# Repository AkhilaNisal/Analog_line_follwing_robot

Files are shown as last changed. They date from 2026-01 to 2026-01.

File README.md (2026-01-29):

# 🛣️ Analog Line Following Robot (Fully Analog PID)

<p align="center">
  <b>A microcontroller-free line following robot using pure analog signal processing</b>
</p>

<p align="center">
  Designed & built by <b>Team Outlaws</b> <br>
  Department of Electronic & Telecommunication Engineering <br>
  University of Moratuwa, Sri Lanka
</p>

---

## 🎥 Full Demo Video

<p align="center">
  <a href="Media/Media1.mp4">
    
  </a>
  <a href="Media/circle.mp4">
    
  </a>
</p>

---

## 📸 Robot Overview

### Front View & PCB
<p align="center">
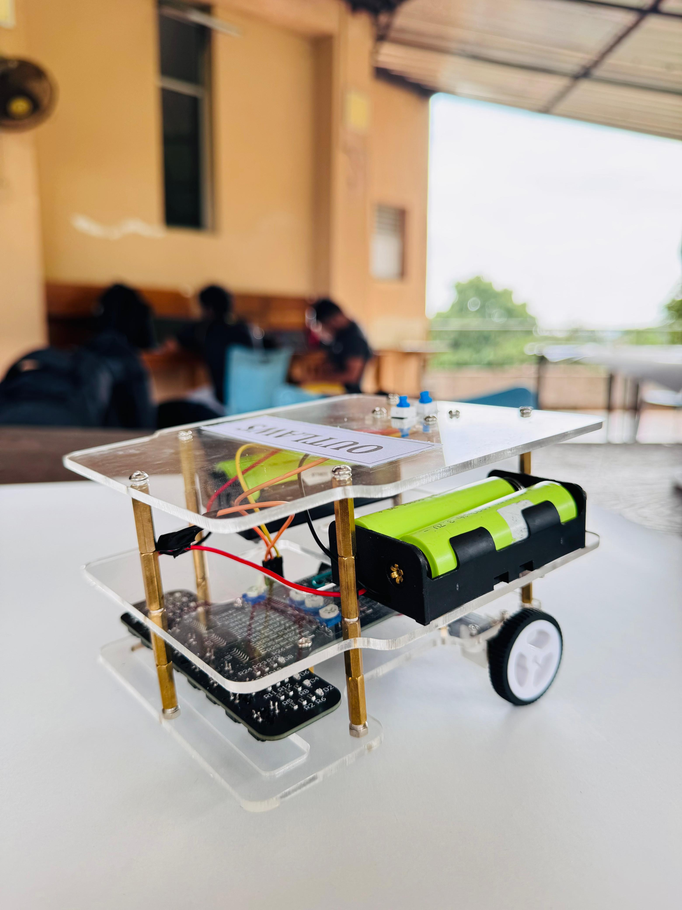
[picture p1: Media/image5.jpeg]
  

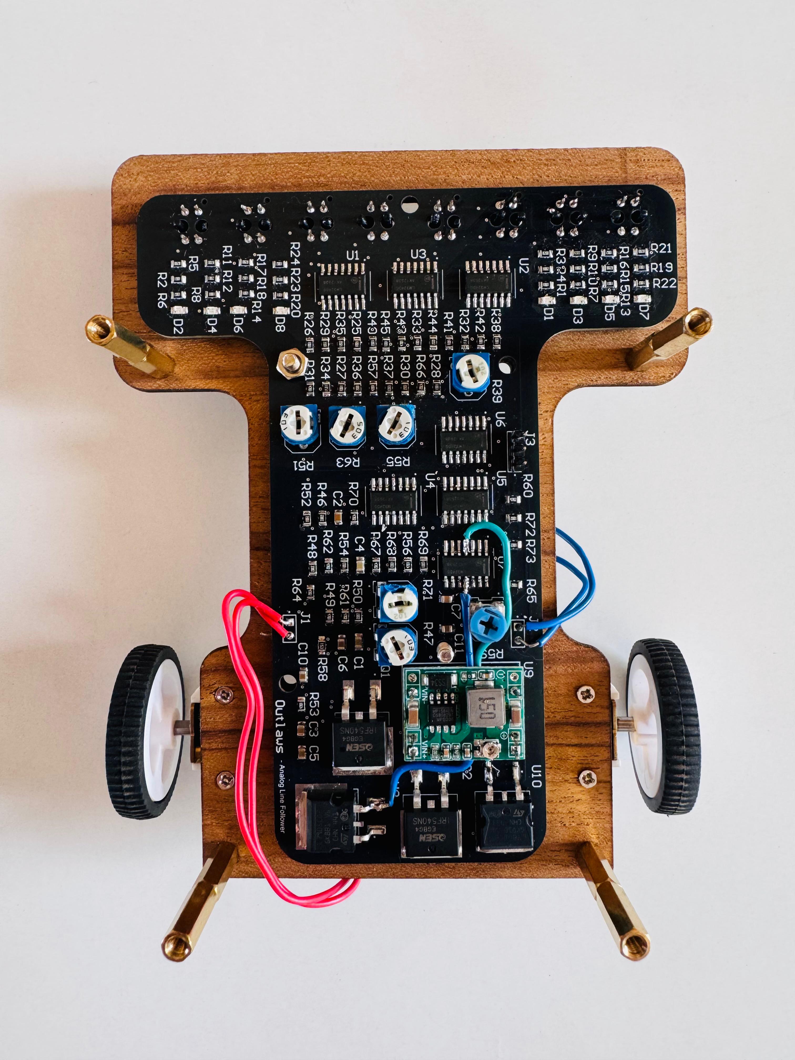
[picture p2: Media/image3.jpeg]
  
</p>

---

## 🧠 System Architecture (Purely Analog)

This project presents a **fully analog line-following robot**, where **all sensing, control,
and actuation are implemented using analog circuits only** — no microcontroller, no
firmware, and no digital computation.

The system operates as follows:

- **8-channel IR sensor array (TCRT5000)** generates continuous analog voltages
- **Buffer circuits** isolate sensor outputs
- **Weighted scaling adders** compute left and right positional values
- **Differential amplifier** produces the line error signal
- **Fully analog PID controller (LM324)** computes corrective action
- **Analog PWM generator** (triangle wave + comparator) converts control signal to PWM
- **Transistor-based motor drivers** actuate DC motors

This architecture enables **real-time, low-latency, deterministic control**.

---

## ⚙️ Key Features

- 🔌 **100% Analog Control System**
- 📡 **Continuous sensor feedback**
- 🎚️ **Adjustable P, I, D gains**
- ⚡ **Low-latency real-time response**
- 🧩 **Custom 2-layer SMD PCB**
- 🖨️ **3D-printed enclosure**
- 🧪 **Simulation-verified & hardware-tested**

---

## 🖥️ Simulation & Hardware Testing

- PID stability verified through circuit simulation
- PWM waveform validated using oscilloscope measurements
- Smooth line tracking with minimal overshoot

---

## 🧑‍🤝‍🧑 Team Outlaws

<p>
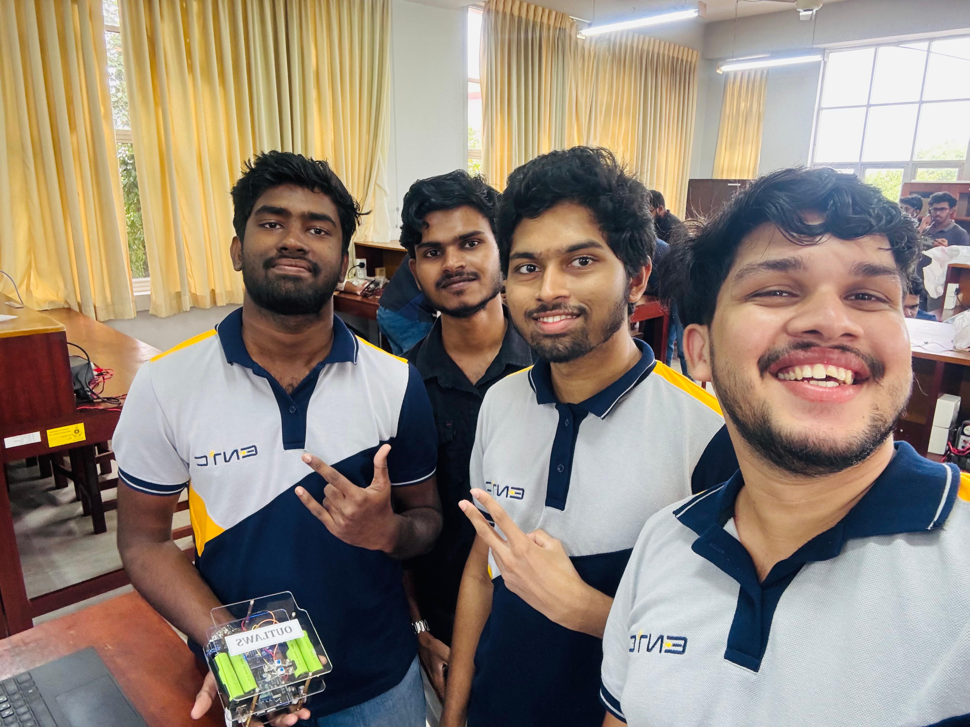
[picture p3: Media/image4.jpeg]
  
</p>

| Name | Index No | Contribution |
|---|---|---|
| A.N. Wedamestrige | 230687P | Circuit design, simulation & debugging |
| R.J.K.O.H. Ranathunga | 230525U | Circuit analysis & enclosure design |
| M.N. Kumarasinghe | 230355X | PCB design |
| W.V.M.J. Himasara | 230248X | Soldering & hardware testing |

---

## 📄 Documentation

📘 Full technical report available in this repository:  
`17_Outlaws_EN2091_Analog_Project.pdf`

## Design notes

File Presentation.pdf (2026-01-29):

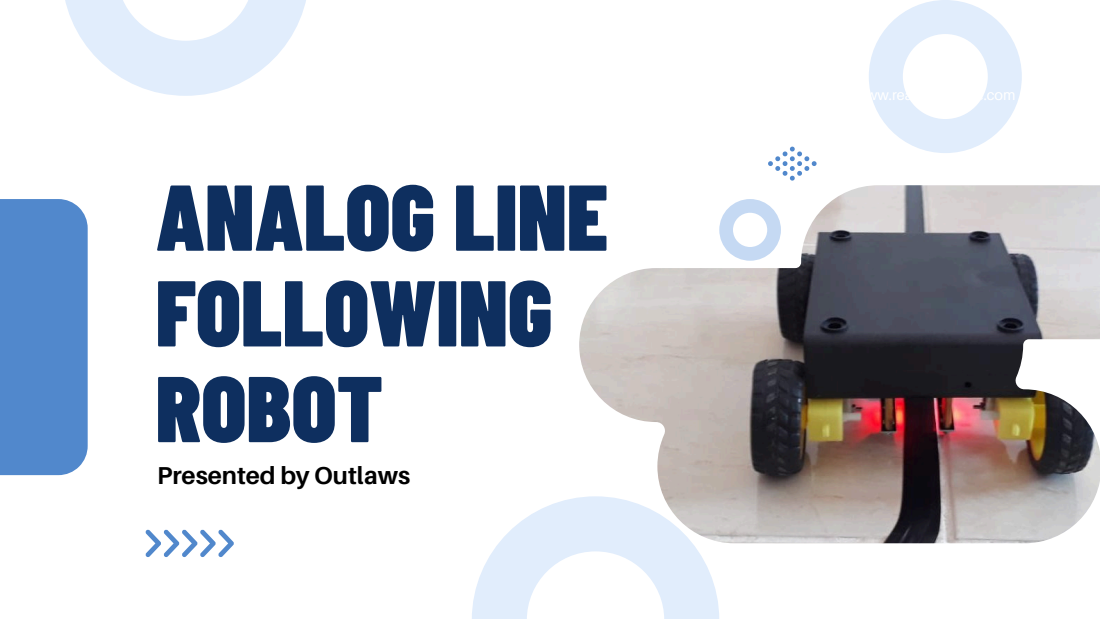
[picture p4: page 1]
ANALOG LINE FOLLOWING ROBOT

www.reallygreatsite.com

Presented by Outlaws

# Project Overview

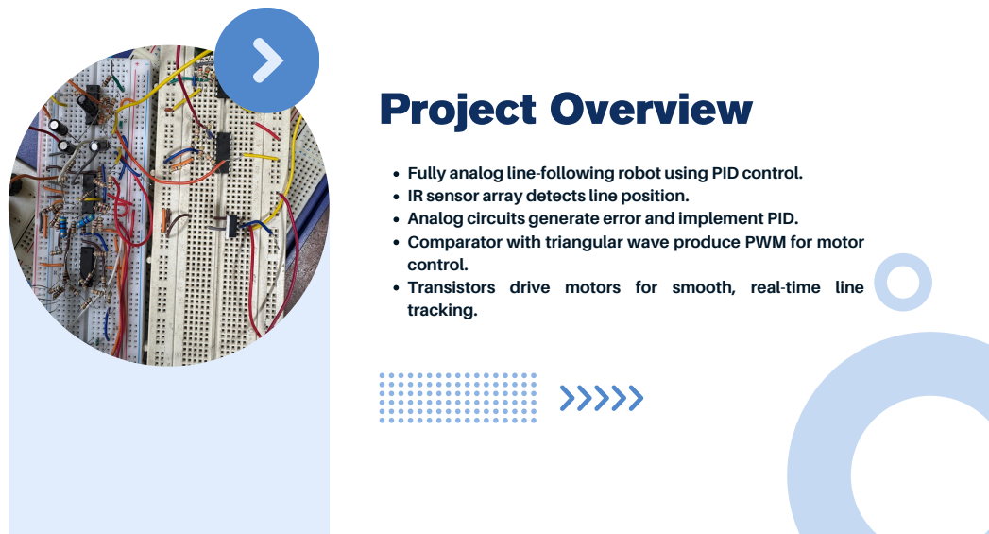
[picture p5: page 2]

Fully analog line-following robot using PID control.
IR sensor array detects line position.
Analog circuits generate error and implement PID.
Comparator with triangular wave produce PWM for motor
control.
Transistors drive motors for smooth, real-time line
tracking.

# Components and Selection

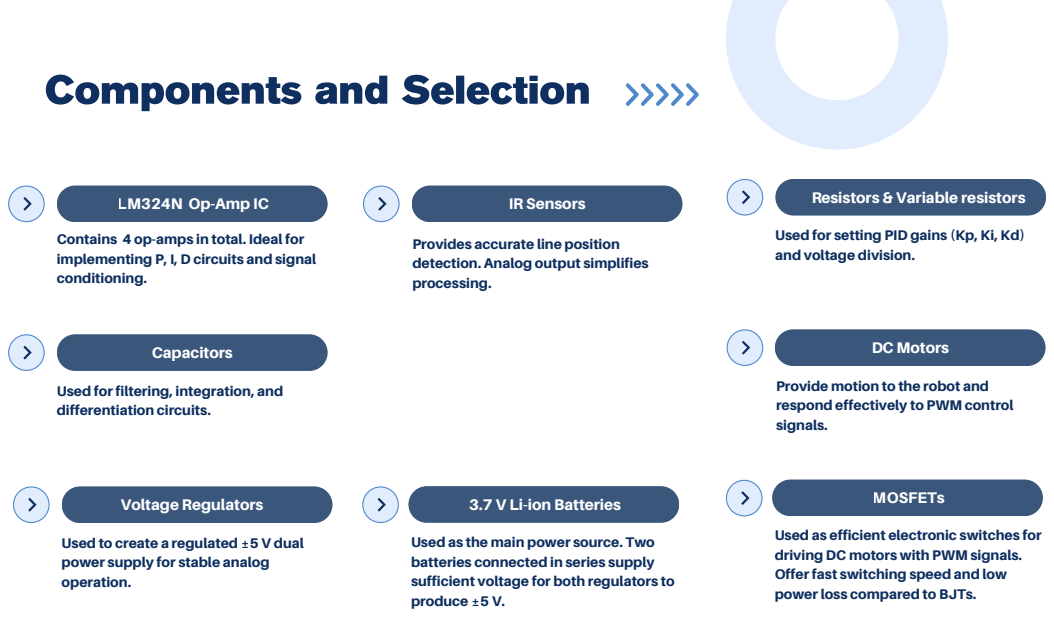
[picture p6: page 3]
IR Sensors; Capacitors; Voltage Regulators; DC Motors; MOSFETs

Resistors & Variable resistors

LM324N Op-Amp IC

Used for setting PID gains (Kp, Ki, Kd)
and voltage division.

Contains 4 op-amps in total. Ideal for
implementing P, I, D circuits and signal
conditioning.

Provides accurate line position
detection. Analog output simplifies
processing.

Provide motion to the robot and
respond effectively to PWM control
signals.

Used forfiltering, integration, and
differentiation circuits.

3.7 V Li-ion Batteries

Used as efficient electronic switches for
driving DC motors with PWM signals.
Offerfast switching speed and low
powerloss compared to BJTs.

Used as the main power source. Two
batteries connected in series supply
sufficient voltage for both regulators to
produce ±5 V.

Used to create a regulated ±5 V dual
power supply for stable analog
operation.

# System Block Diagram

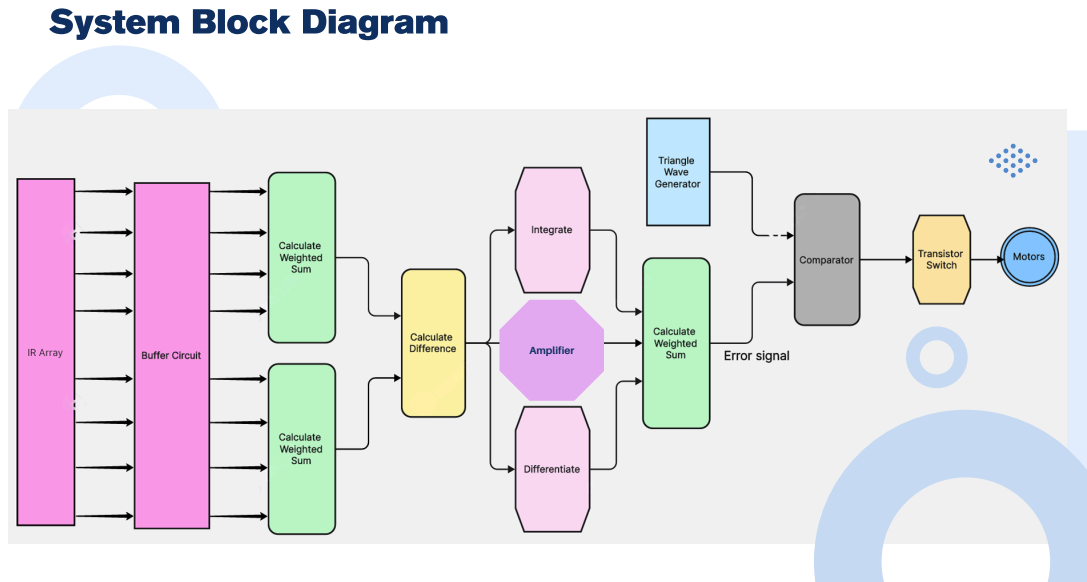
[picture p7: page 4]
Amplifier

# Functionality

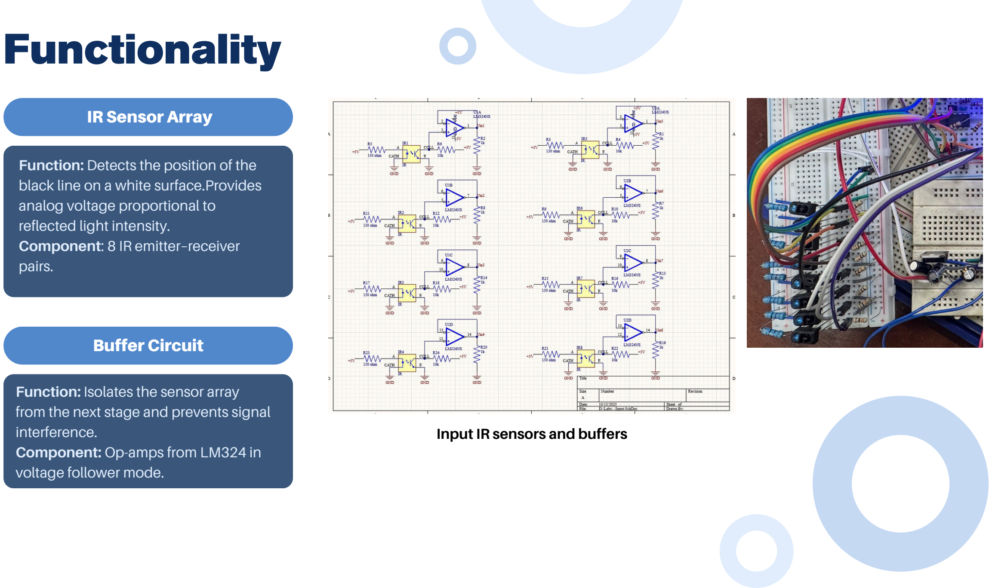
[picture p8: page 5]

Buffer Circuit

Function: Detects the position of the black line on a white surface.Provides analog voltage proportional to reflected light intensity.
Component: 8 IR emitter–receiver pairs.

IR Sensor Array

Function: Isolates the sensor array from the next stage and prevents signal interference.
Component: Op-amps from LM324 in voltage follower mode.

Input IR sensors and buffers

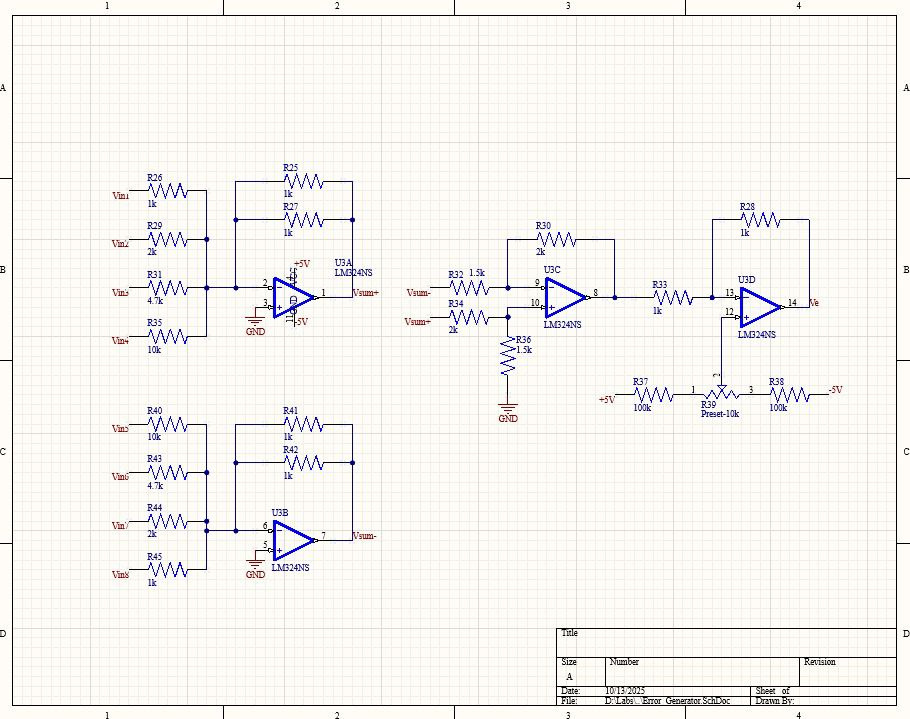
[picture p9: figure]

Scaling adders and Subtractor

Weighted Sum Calculation

Function: Computes position information by giving different weights to each sensor.
Component: Scaling adder circuit using op-amps and resistors.

Calculate Difference

Function: Produces the error signal by comparing left and right sums. Component: Differential amplifier

# Functionality

# Functionality

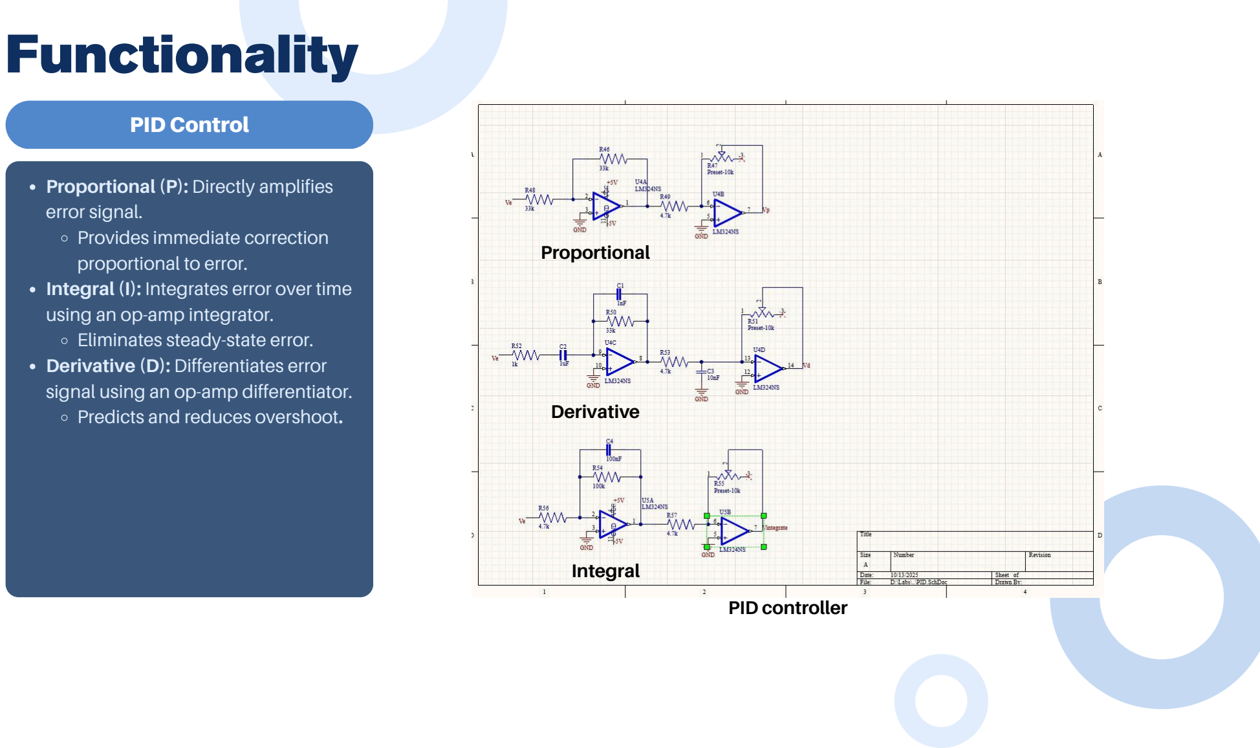
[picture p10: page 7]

PID Control

Proportional (P): Directly amplifies error signal.
Provides immediate correction proportional to error.
Integral (I): Integrates error over time using an op-amp integrator. Eliminates steady-state error. Derivative (D): Differentiates error signal using an op-amp differentiator. Predicts and reduces overshoot.

PID controller

Proportional

Derivative

Integral

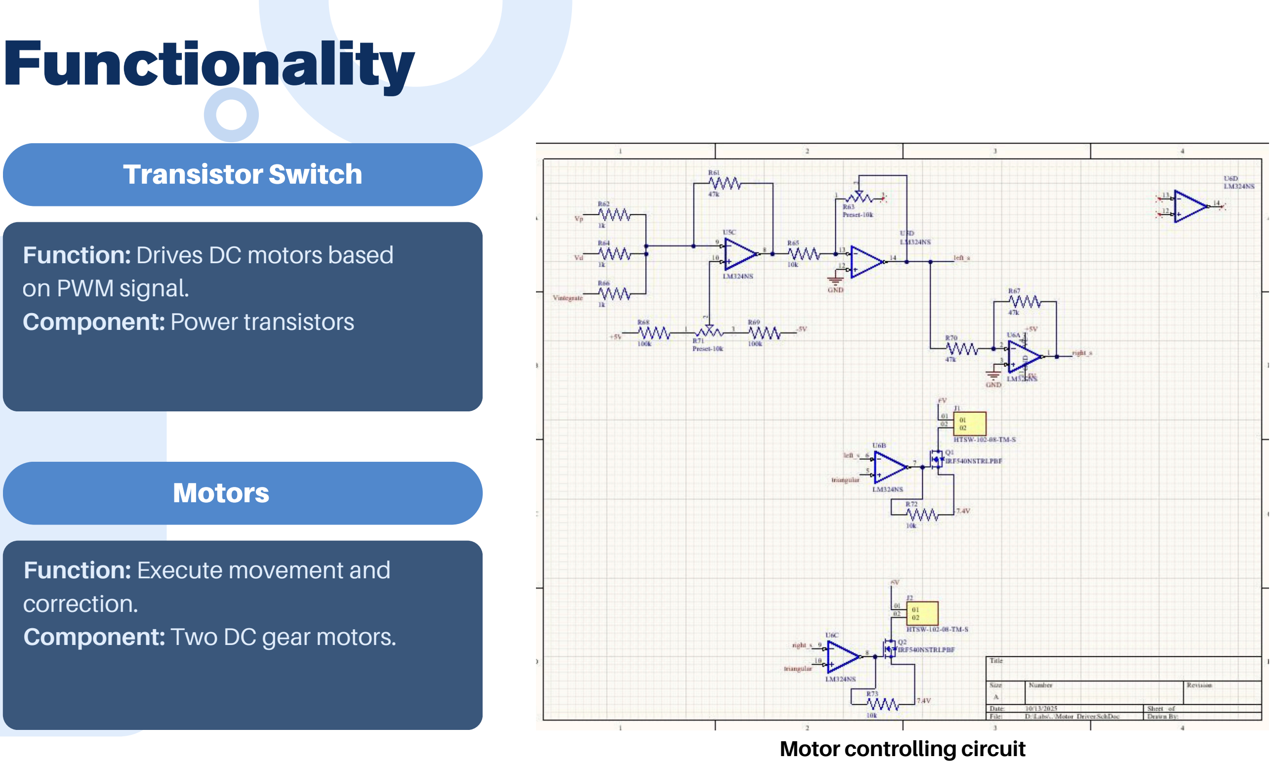
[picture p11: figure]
Transistor Switch; on PWM signal.; Motors; Function: Execute movement and correction. Component: Two DC gear motors.; Motor controlling circuit; Functionality

Function: Drives DC motors based Component: Power transistors

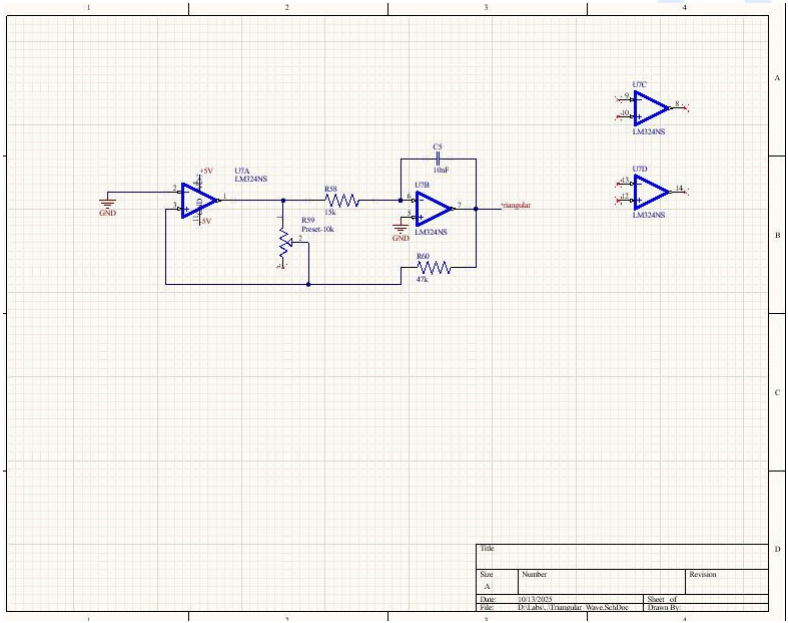
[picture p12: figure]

Triangular wave generator

## Comparator

Function: Produces a periodic triangle waveform.
Component: Op-amp-based
integrator + comparator.

## Triangle Wave Generator

Function: Compares PID output with triangle wave to generate PWM. Component: Op-amp in comparator mode.

# Functionality

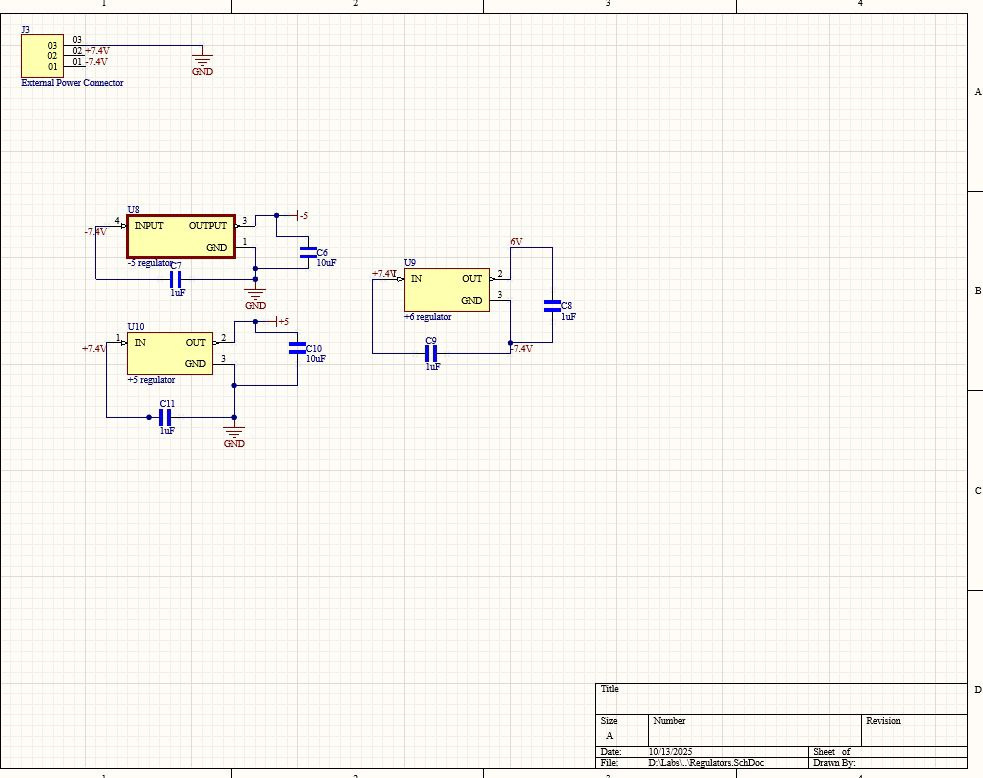
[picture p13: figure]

Regulators and power management circuits

# PCB Design

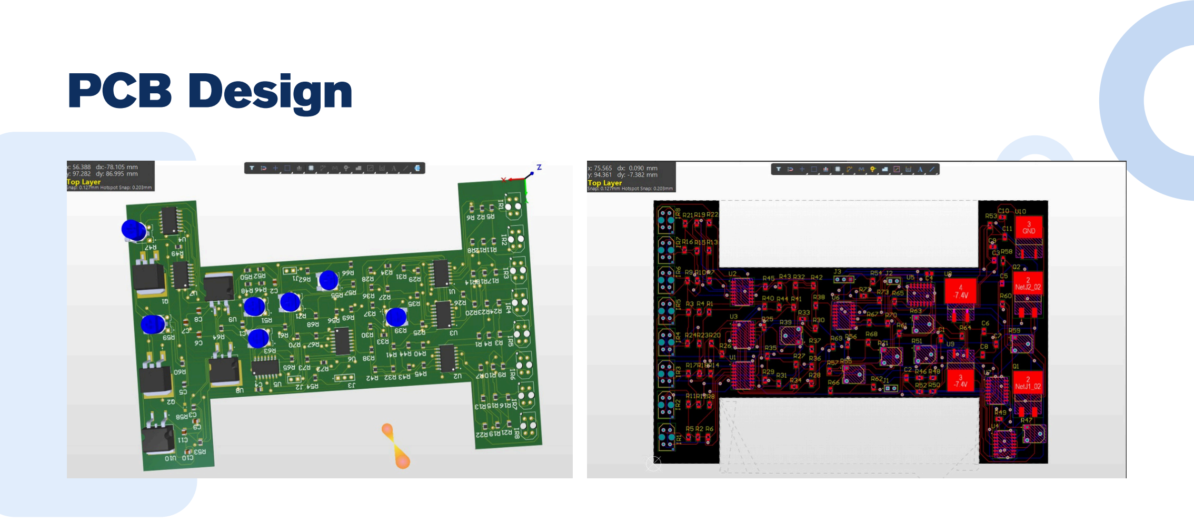
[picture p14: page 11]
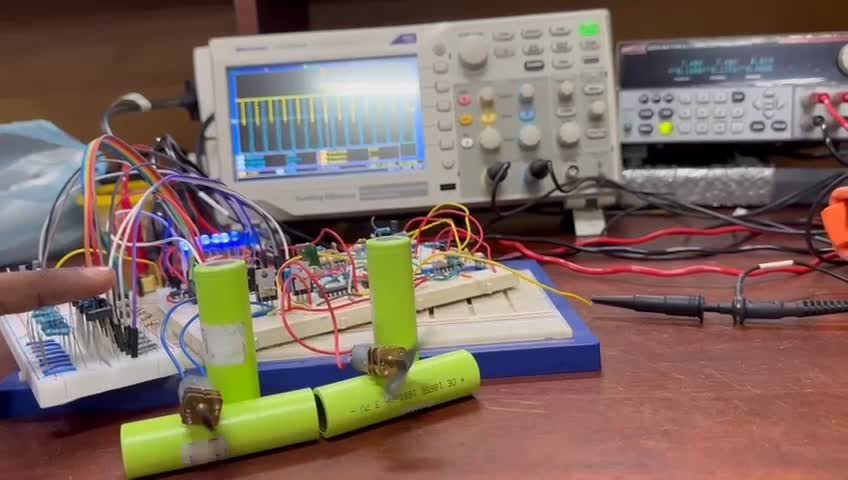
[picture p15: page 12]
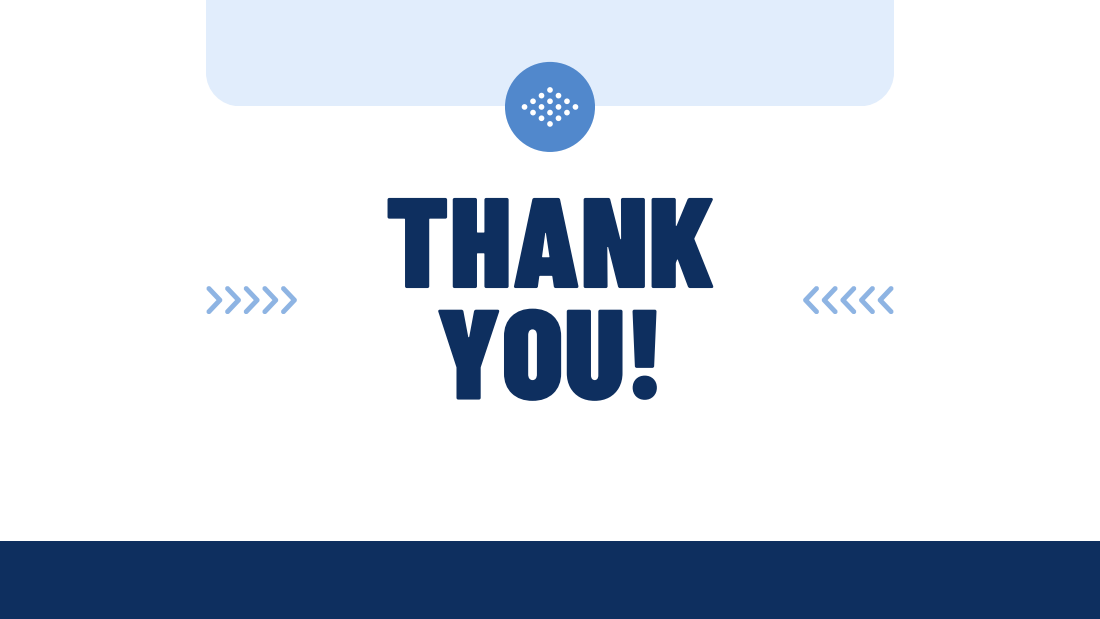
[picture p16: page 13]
THANK YOU!

www.reallygreatsite.com

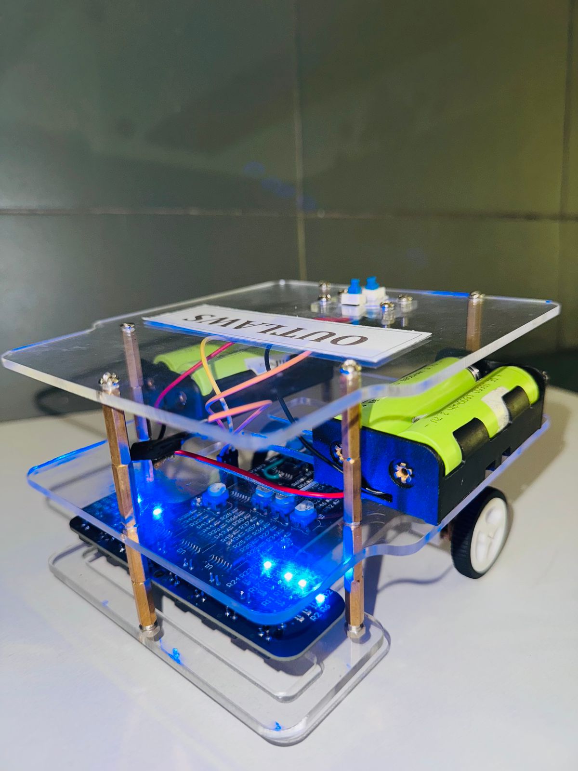
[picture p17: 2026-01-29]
Media/image.jpg

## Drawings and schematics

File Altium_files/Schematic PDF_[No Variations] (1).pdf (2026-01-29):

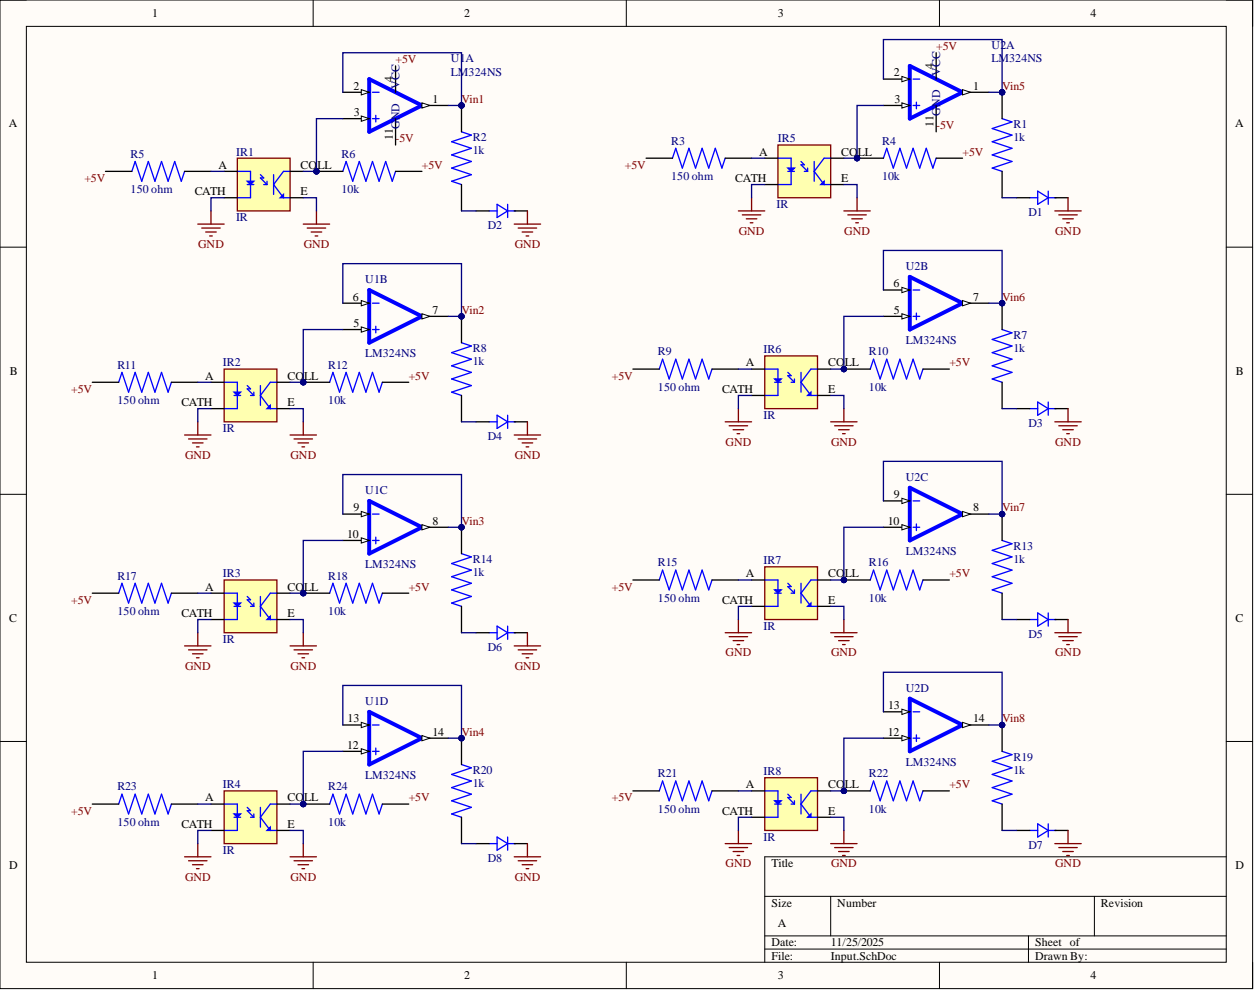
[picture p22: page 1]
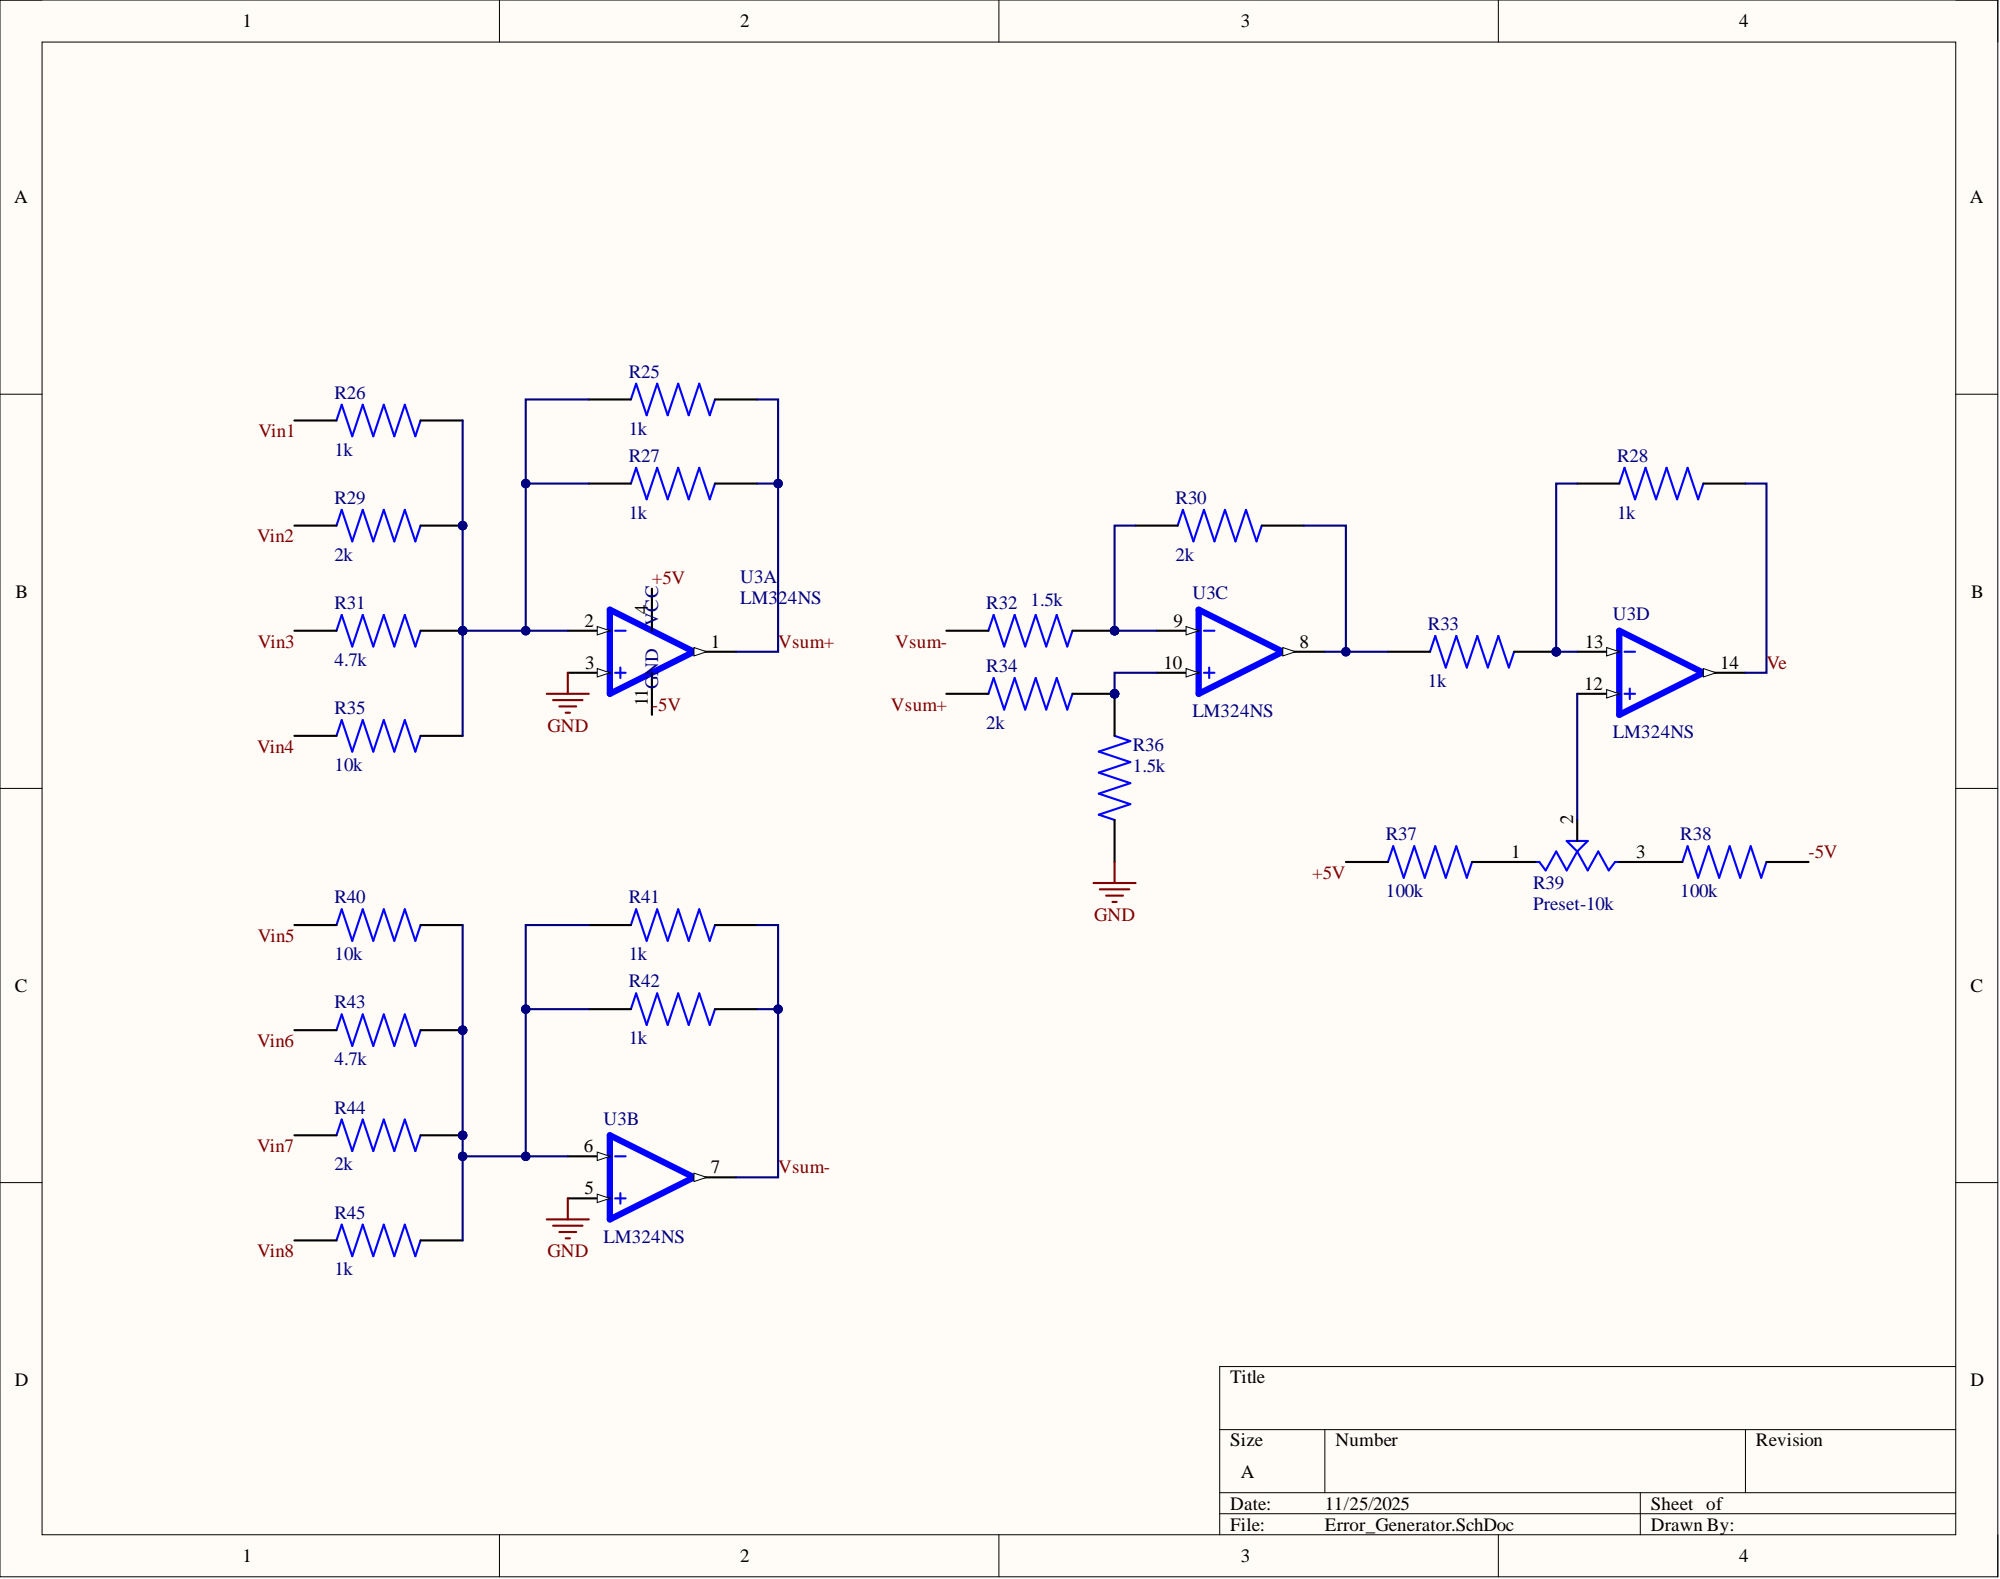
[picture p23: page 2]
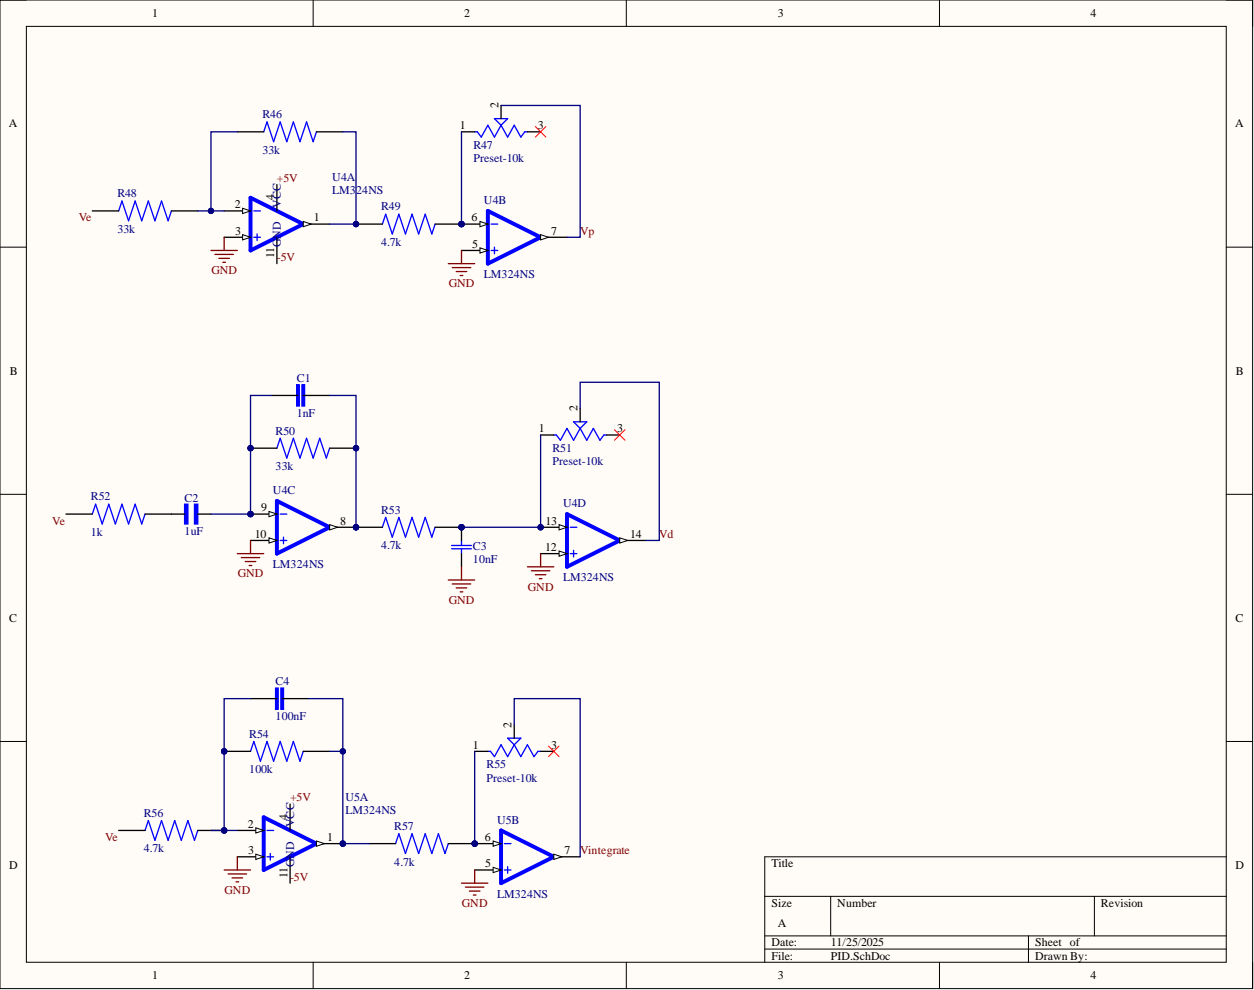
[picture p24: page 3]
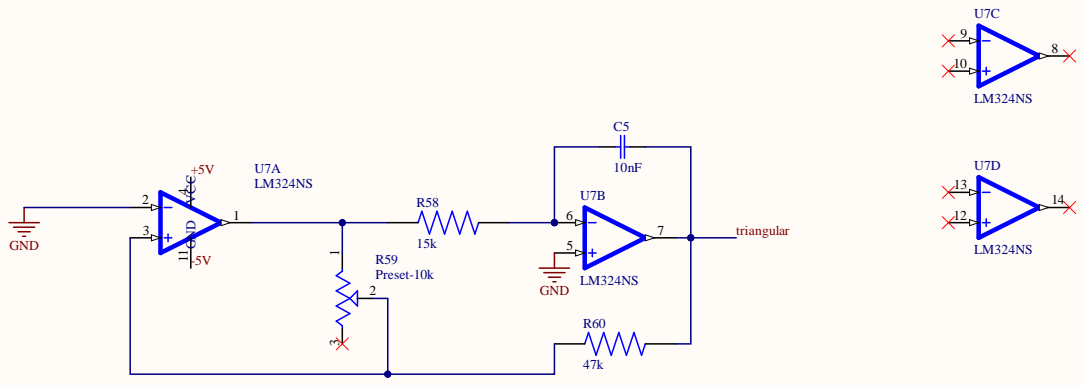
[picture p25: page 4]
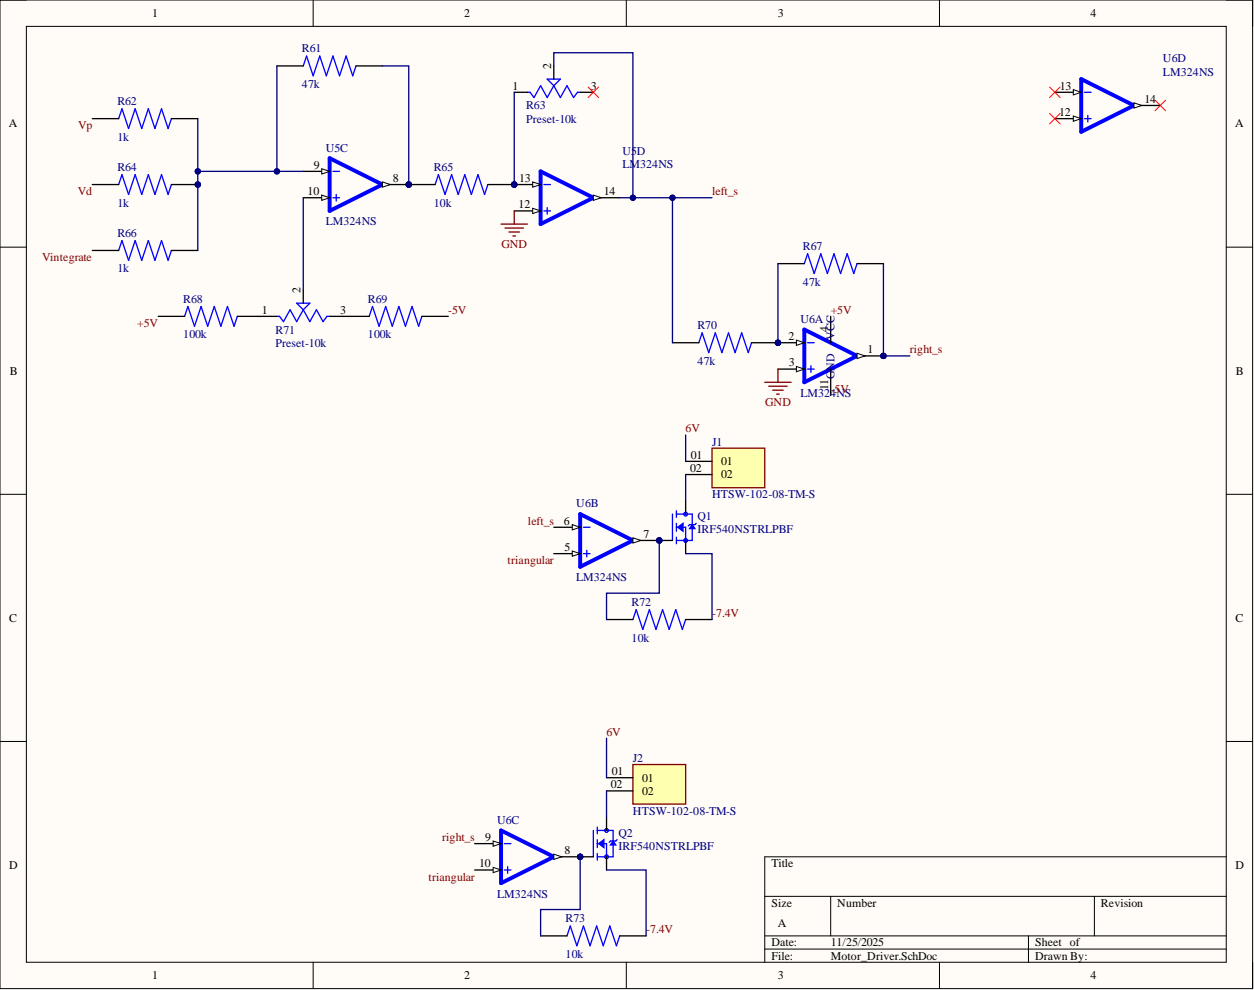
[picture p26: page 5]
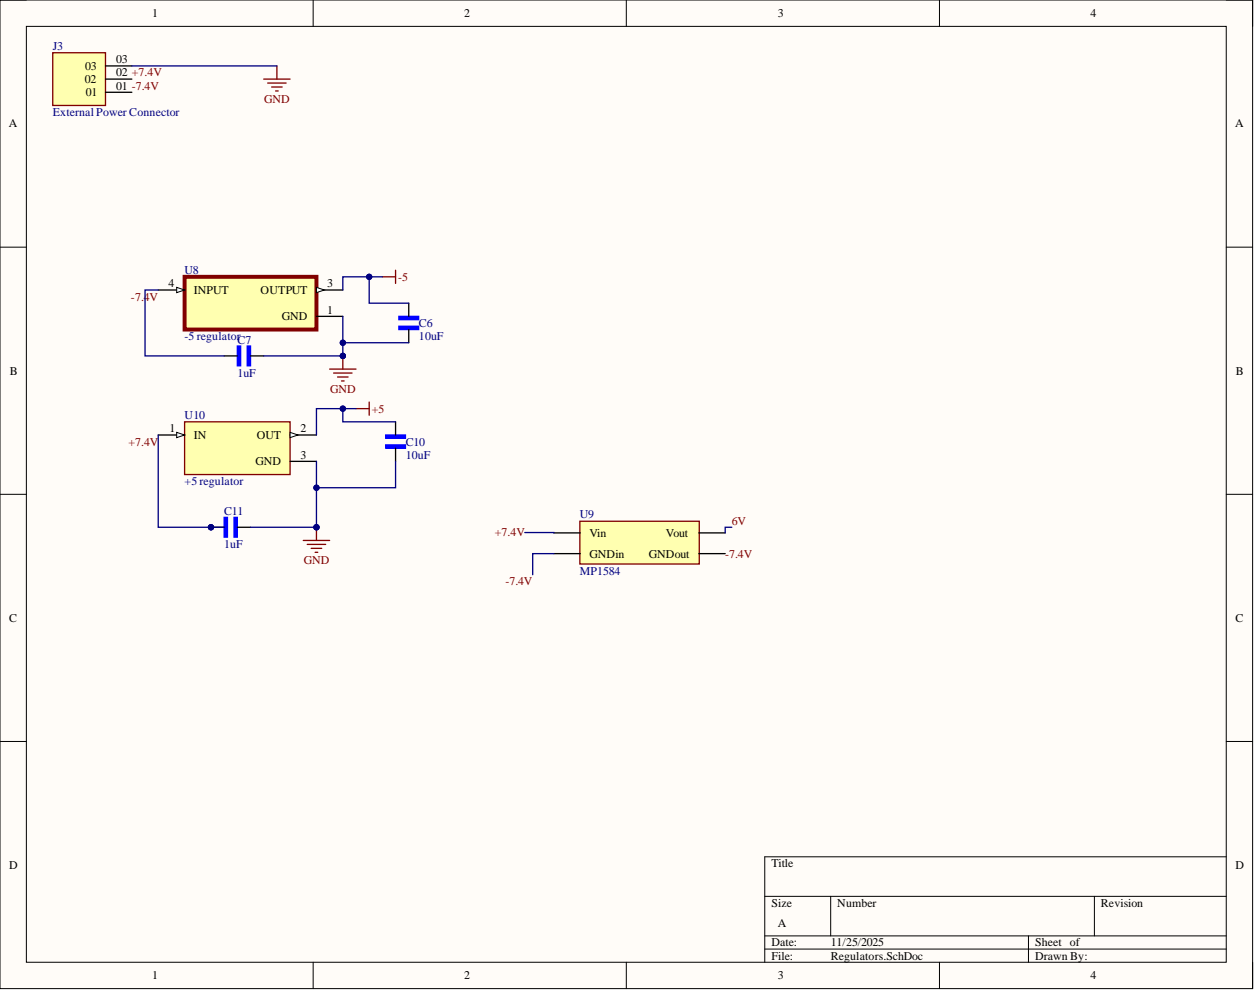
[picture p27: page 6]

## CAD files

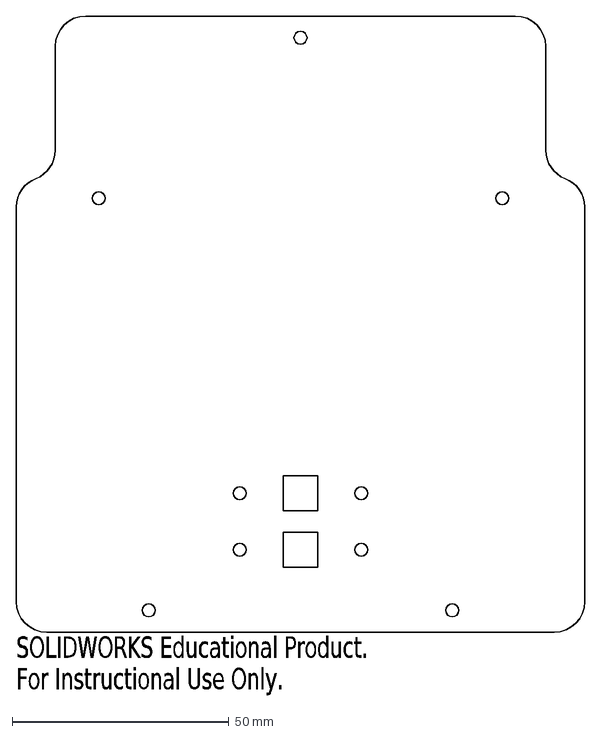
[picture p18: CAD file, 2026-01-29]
Solidworks/upper_top.DXF
SOLIDWORKS Educational Product.
For Instructional Use Only.

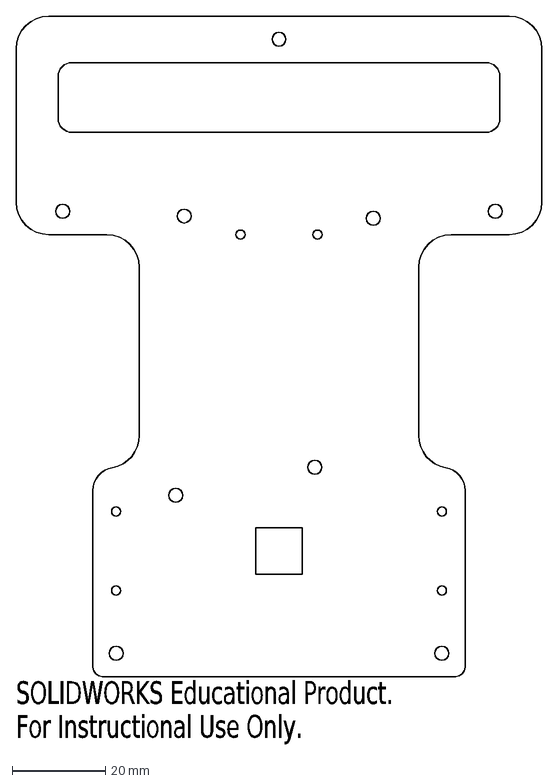
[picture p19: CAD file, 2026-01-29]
Solidworks/lower.DXF
SOLIDWORKS Educational Product.
For Instructional Use Only.

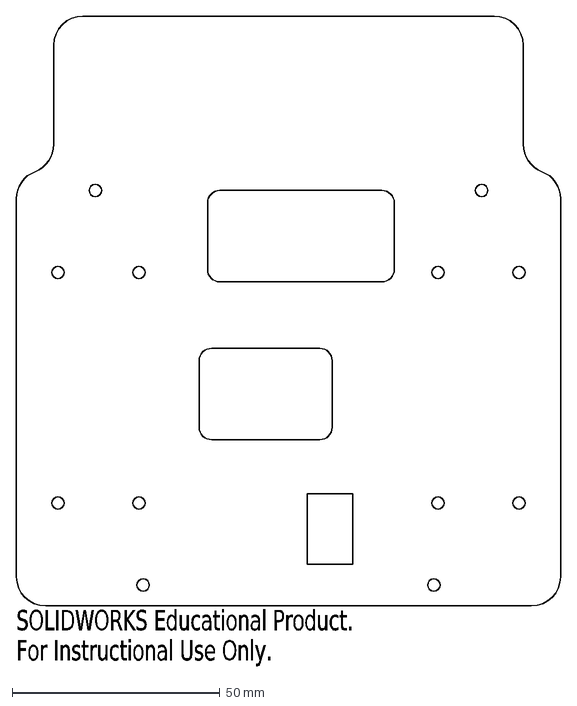
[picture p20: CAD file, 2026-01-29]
Solidworks/upper_acrilic.DXF
SOLIDWORKS Educational Product.
For Instructional Use Only.

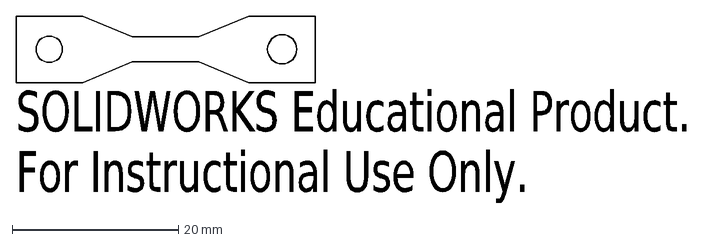
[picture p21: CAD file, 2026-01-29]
Solidworks/bracket1.DXF
SOLIDWORKS Educational Product.
For Instructional Use Only.
